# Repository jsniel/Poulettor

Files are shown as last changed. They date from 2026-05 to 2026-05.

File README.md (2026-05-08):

# 🐔 Poulettor

**Open-source automatic chicken coop door controller**

Autonomous ESP32-C3 controller for opening and closing a chicken coop door using a simple DC motor, limit switches and a local Wi‑Fi web interface.

---

## Description

Poulettor is an open-source chicken coop door controller designed to automate a simple sliding or lifting door.

The project uses an **ESP32-C3 Mini**, a **DS3231 RTC**, two relay modules and two limit switches to safely drive a small DC motor in both directions.

Opening and closing times are automatically calculated from local sunrise and sunset, with configurable time offsets from the web interface.

The system is designed to be simple, repairable and independent from the cloud.

---

## Features

- Automatic opening based on sunrise
- Automatic closing based on sunset
- Adjustable morning and evening offsets
- Manual opening button
- Manual closing button
- Local Wi‑Fi configuration portal
- RTC-based scheduling with DS3231
- DC motor control through relays
- Top and bottom limit switch detection
- Motor timeout protection
- Status LED feedback
- No cloud required

---

## Hardware

### Required

- ESP32-C3 Mini
- DS3231 RTC module
- 2 × 5V relay modules
- Small DC gear motor
- 2 × limit switches
- 2 × push buttons
- Status LED + resistor
- Custom PCB or hand wiring
- 5V power source or USB power bank
- Mechanical door, spool, cord and guides

### Enclosure

3D printable enclosure files
- BoitePorte-Corps001.stl
- BoitePorte-Corps002.stl

Editable project with Freecad
- BoitePorte.FCStd

---

## PCB / Electronics

<p align="center">
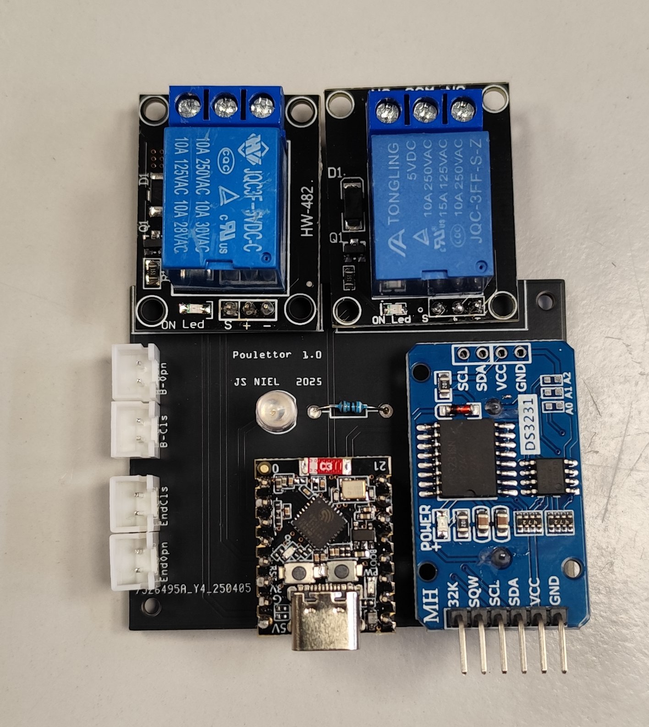
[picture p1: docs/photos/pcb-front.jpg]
  
</p>
<p align="center">
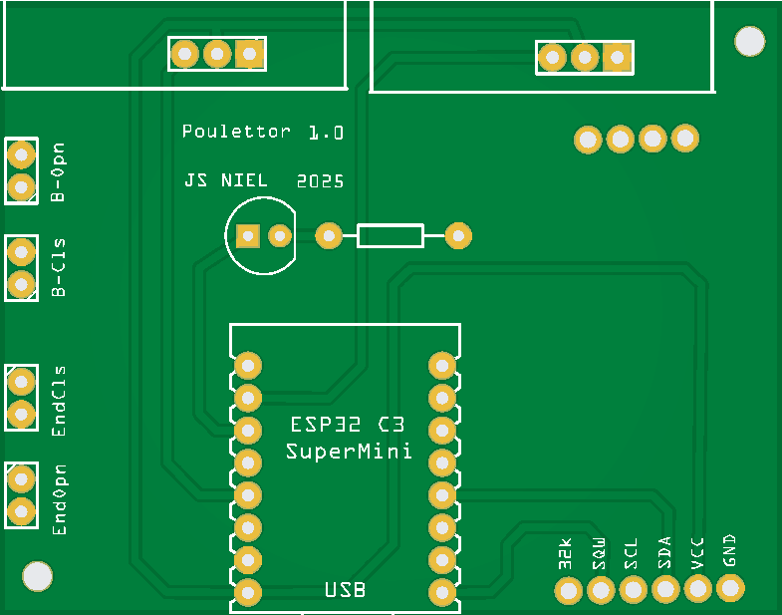
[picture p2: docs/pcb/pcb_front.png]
  
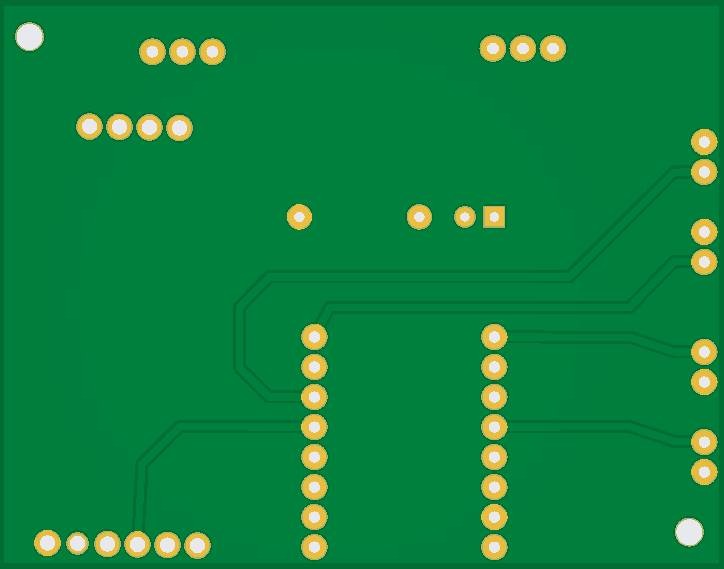
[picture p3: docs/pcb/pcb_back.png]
  
</p>

Hardware files are available in:

```txt
hardware/
```

---

## Prototype Photos

<p align="center">
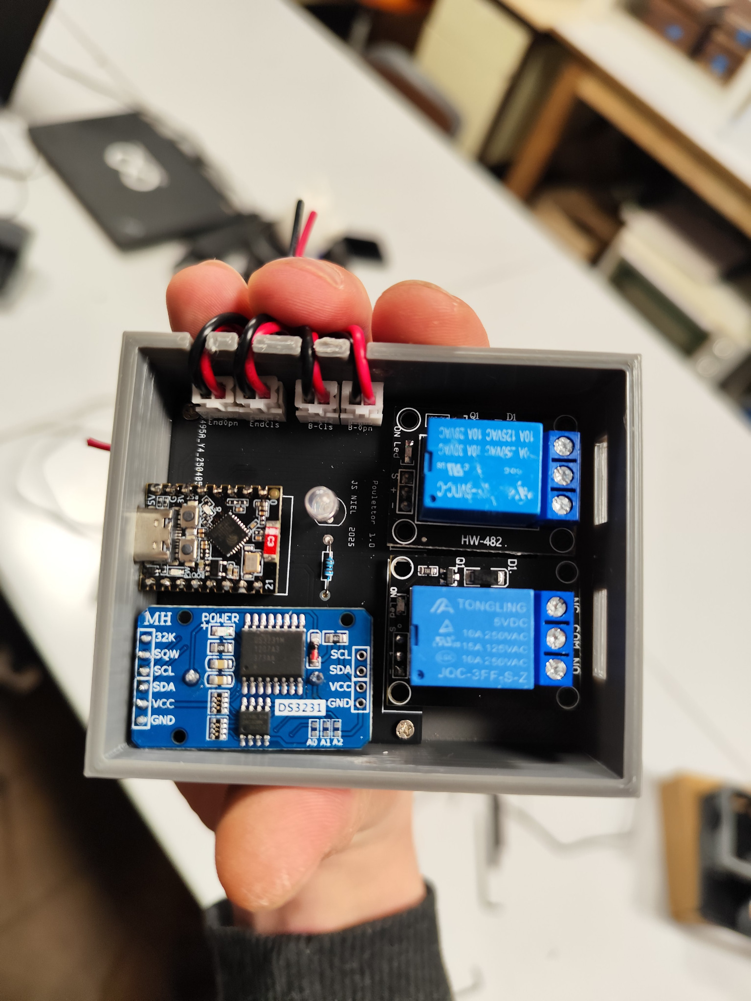
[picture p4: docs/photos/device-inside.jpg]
  
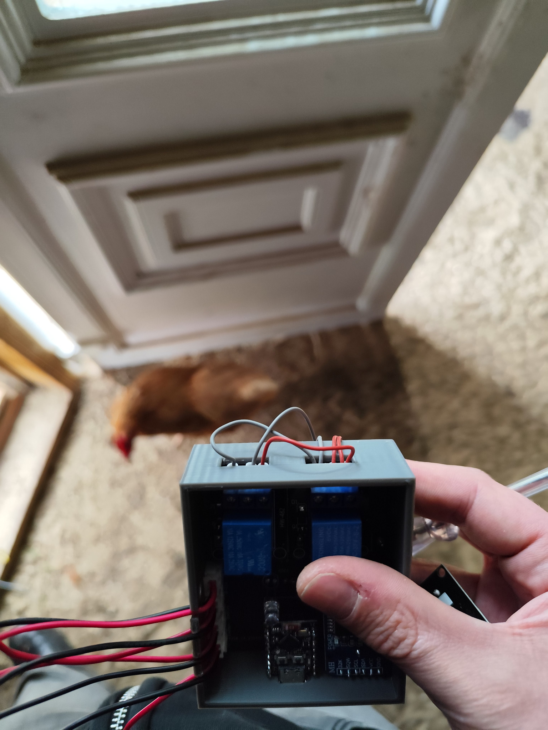
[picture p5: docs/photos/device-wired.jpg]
  
</p>

<p align="center">
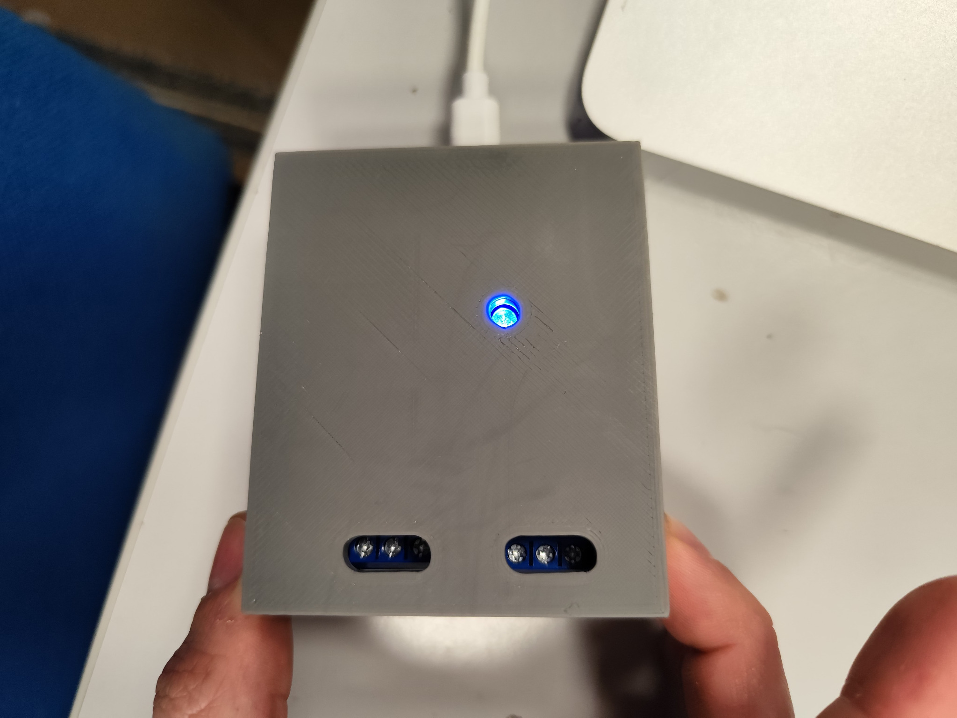
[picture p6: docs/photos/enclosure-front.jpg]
  
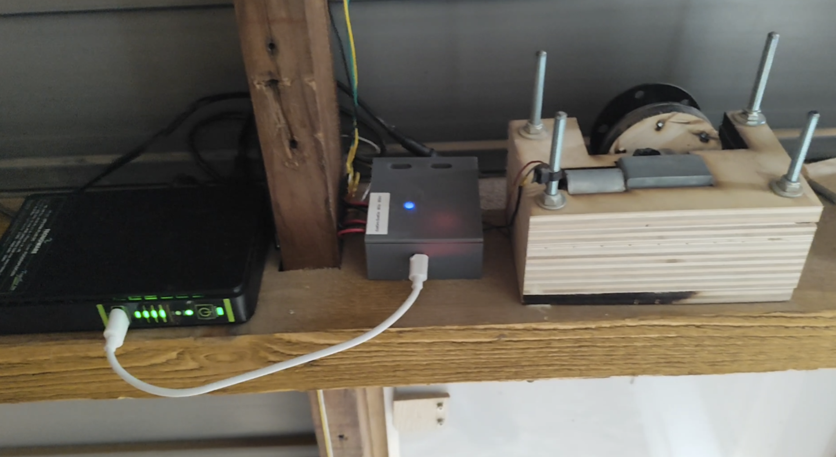
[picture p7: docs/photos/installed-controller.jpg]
  
</p>

---

## Door Mechanism

The door is moved by a simple DC motor and spool mechanism.

<p align="center">
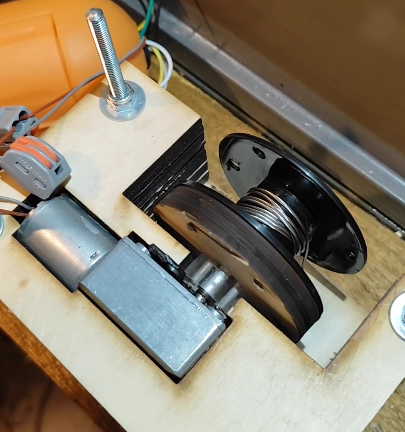
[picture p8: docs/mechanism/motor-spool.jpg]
  
</p>

Two limit switches are used:

- top limit switch: door fully open;
- bottom limit switch: door fully closed.

The firmware stops the motor when a limit switch is reached or after a safety timeout.

---

## Web Interface

You can:

- open the door manually;
- close the door manually;
- view current RTC date and time;
- view calculated sunrise and sunset times;
- configure morning and evening offsets;
- set the RTC time.

<p align="center">
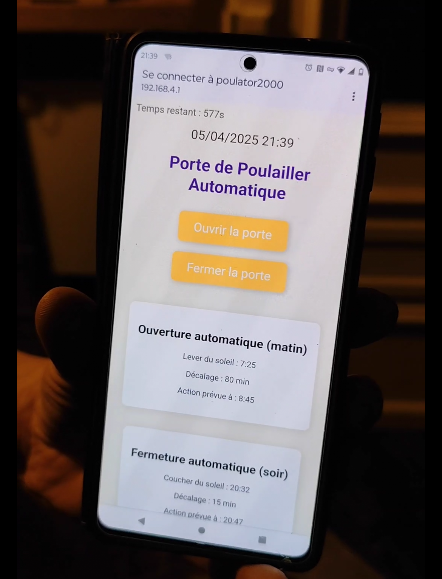
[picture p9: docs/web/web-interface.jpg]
  
</p>

---

## Buttons and LED

### Open / Wi‑Fi button

A short press opens the door manually.

A long press starts the Wi‑Fi configuration portal.

### Close button

A short press closes the door manually.

### LED behavior

| LED behavior | Meaning |
|---|---|
| Solid ON | Automatic mode available |
| Double blink pattern | Wi‑Fi portal active |
| Slow blinking | RTC error |
| Fast blinking | Motor timeout error |

---

## Wi‑Fi portal

Default access point:

```txt
SSID: poulator2000
Password: 123456789
Address: http://192.168.4.1
```

The portal is started with a long press on the open/Wi‑Fi button.

---

## Firmware

Location:

```txt
firmware/PoulettorFW/PoulettorFW.ino
```

---

## Arduino IDE Setup (ESP32‑C3)

### 1. Add ESP32 boards

Open Arduino IDE:

- Go to **File → Preferences**
- In **Additional Boards Manager URLs**, add:

```txt
https://raw.githubusercontent.com/espressif/arduino-esp32/gh-pages/package_esp32_index.json
```

---

### 2. Install ESP32 package

- Go to **Tools → Board → Boards Manager**
- Search: `esp32`
- Install:

```txt
esp32 by Espressif Systems
```

Tested version:

```txt
3.3.5
```

---

### 3. Select board

```txt
ESP32C3 Dev Module
```

---

### 4. Required libraries

Install from Arduino Library Manager:

| Library | Tested version |
|---|---:|
| RTClib by Adafruit | 2.1.4 |
| Adafruit BusIO | 1.17.4 |

---

## Usage

### First boot

1. Power the controller.
2. Hold the open/Wi‑Fi button for about 3 seconds.
3. Connect to the Wi‑Fi access point.
4. Set the RTC time.
5. Configure sunrise and sunset offsets if needed.

---

### Manual control

- Short press on the open button: open the door.
- Short press on the close button: close the door.
- Web interface buttons can also open or close the door.

---

## Known Issues

- No battery level monitoring.
- Wi‑Fi portal has no authentication beyond the AP password.
- Location is currently hardcoded in the firmware.
- The enclosure is a prototype.
- The mechanism must be adapted to each chicken coop door.

---

## Project Structure

```txt
Poulettor/
├── firmware/
├── hardware/
├── enclosure-stl/
├── mechanical/
├── docs/
├── LICENSES/
├── README.md
└── LICENSE
```

---

## Author

**Jean-Sébastien Niel**

GitHub:  
https://github.com/jsniel

---

## License

Poulettor uses separate licenses for firmware and hardware.

### Firmware

GNU General Public License v3.0 or later

```txt
GPL-3.0-or-later
```

### Hardware

CERN Open Hardware Licence Version 2 - Strongly Reciprocal

```txt
CERN-OHL-S-2.0
```

---

## ⚠️ Disclaimer

This project controls a moving mechanical door.

Always test the mechanism safely before using it with animals.

Make sure the door cannot injure animals, block unexpectedly, or trap a chicken during closing.

This project is provided without warranty.

---

## Contributing

Pull requests, mechanical improvements, PCB improvements and firmware improvements are welcome.

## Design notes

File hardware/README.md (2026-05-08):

# Hardware

This directory contains the hardware design files for Poulettor.

---

## Files

| Path | Description |
|---|---|
| `fritzing/PoulaillerPorteGND.fzz` | Fritzing project |
| `pcb/gerber/` | Gerber and drill files |

---

## Hardware overview

The controller uses an ESP32-C3 Mini, a DS3231 RTC, two relay modules and two limit switches.

One relay drives the motor in the opening direction.  
The other relay drives the motor in the closing direction.

The firmware never intentionally activates both motor directions at the same time.

---

## Limit switches

The two limit switches are wired as inputs with internal pull-ups.

| Limit switch | Function |
|---|---|
| Top endstop | Door fully open |
| Bottom endstop | Door fully closed |

Active state is `LOW`.

---

## Safety

Use a motor and power supply adapted to the mechanical load.

Always test the complete mechanism before installing it in a coop.

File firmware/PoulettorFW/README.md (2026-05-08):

# Poulettor firmware

ESP32-C3 firmware for the Poulettor automatic chicken coop door controller.

Firmware by Jean-Sébastien Niel.  
GitHub: https://github.com/jsniel

License: GPL-3.0-or-later

---

## Main behavior

- Calculates sunrise and sunset times from hardcoded latitude and longitude.
- Opens the door in the morning using the sunrise time plus an offset.
- Closes the door in the evening using the sunset time plus an offset.
- Stores offsets in EEPROM.
- Drives a DC motor through two relay outputs.
- Stops motion using top and bottom limit switches.
- Stops the motor after a 15-second timeout if no limit switch is reached.
- Provides a local Wi-Fi web interface when requested by button.

---

## Pin mapping

| Function | GPIO |
|---|---:|
| Open / Wi-Fi button | GPIO10 |
| Close button | GPIO21 |
| Status LED | GPIO2 |
| Top limit switch | GPIO3 |
| Motor open relay | GPIO4 |
| Bottom limit switch | GPIO0 |
| Motor close relay | GPIO1 |
| RTC interrupt | GPIO5 |
| SDA | GPIO8 |
| SCL | GPIO9 |

---

## Arduino IDE setup

Add this URL to Arduino IDE Boards Manager:

```txt
https://raw.githubusercontent.com/espressif/arduino-esp32/gh-pages/package_esp32_index.json
```

Install:

```txt
esp32 by Espressif Systems
```

Select:

```txt
ESP32C3 Dev Module
```

---

## Required libraries

| Library | Tested version |
|---|---:|
| RTClib by Adafruit | 2.1.4 |
| Adafruit BusIO | 1.17.4 |

---

## Default Wi-Fi portal

```txt
SSID: poulator2000
Password: 123456789
IP address: 192.168.4.1
```

---

## Web routes

| Route | Description |
|---|---|
| `/` | Main web page |
| `/ouvrir` | Open the door |
| `/fermer` | Close the door |
| `/setoffset` | Save sunrise/sunset offsets |
| `/settime` | Set RTC time |
| `/datetime` | Return current RTC date and time |
| `/time` | Return current RTC time |

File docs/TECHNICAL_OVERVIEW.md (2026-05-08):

# Technical Overview

This document summarizes the firmware behavior.

---

## Scheduling

The firmware computes sunrise and sunset times from:

- date from DS3231 RTC;
- hardcoded latitude;
- hardcoded longitude;
- daylight saving time detection.

Morning and evening offsets are stored in EEPROM.

---

## Movement state machine

Movement states:

- `AUCUN`
- `OUVERTURE_EN_COURS`
- `FERMETURE_EN_COURS`

Opening:

- stops any current movement;
- checks the top limit switch;
- starts the open relay;
- waits for top endstop or timeout.

Closing:

- stops any current movement;
- checks the bottom limit switch;
- starts the close relay;
- waits for bottom endstop or timeout.

---

## Timeout protection

If a movement lasts more than 15 seconds, the firmware stops the motor and enters timeout error state.

The LED then blinks rapidly.

---

## Web portal

The web server is only started after a long button press.

It provides:

- manual open;
- manual close;
- offset configuration;
- RTC time setting;
- date/time display;
- countdown before portal shutdown.

---

## Important notes

The location is currently hardcoded:

```cpp
const float LATITUDE = 49.4687;
const float LONGITUDE = 1.1178;
```

Future versions could expose location configuration in the web interface.

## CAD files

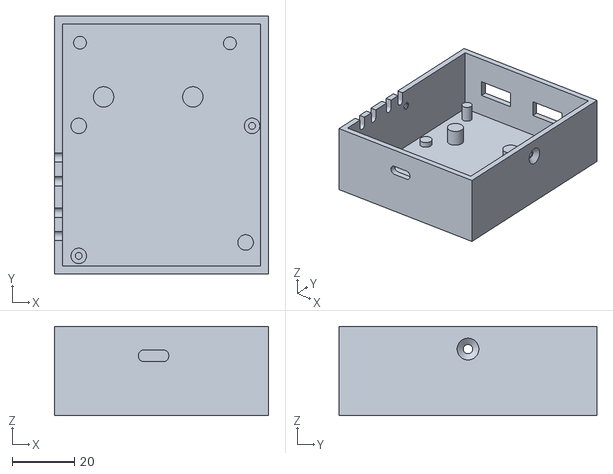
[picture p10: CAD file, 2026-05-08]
enclosure-stl/BoitePorte-Corps001.stl
69.0 x 83.1 x 28.8

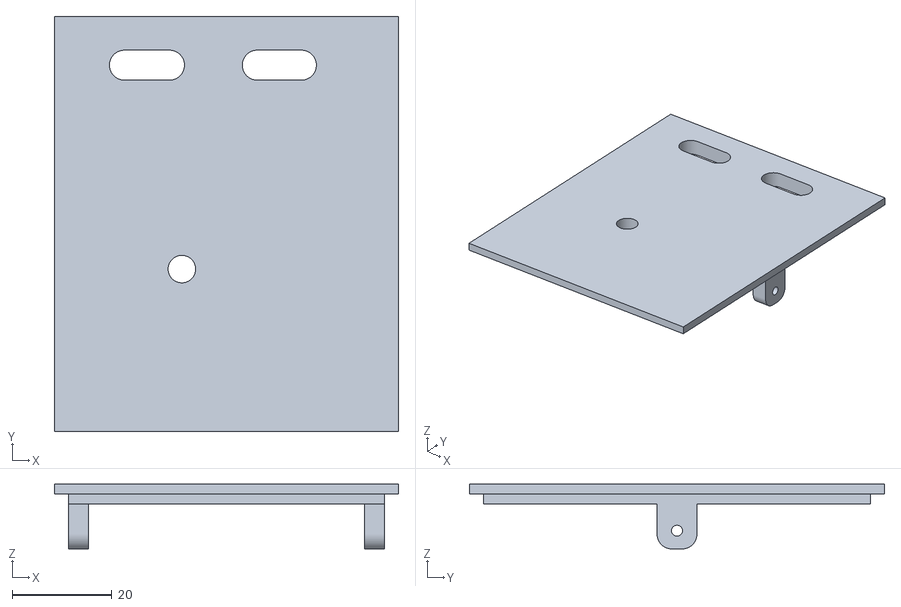
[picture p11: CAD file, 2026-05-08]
enclosure-stl/BoitePorte-Corps002.stl
69.0 x 83.1 x 13.0

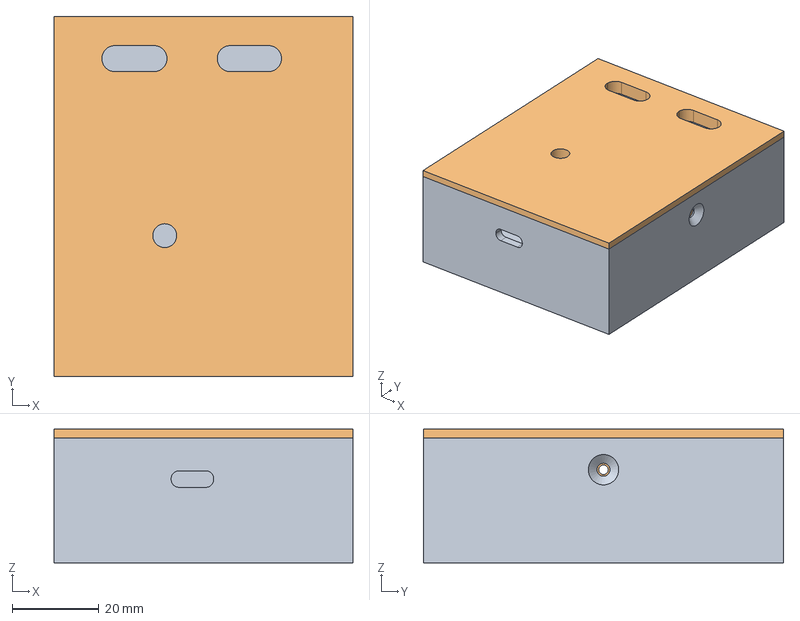
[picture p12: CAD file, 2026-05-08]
enclosure-stl/BoitePorte.FCStd
69.0 x 83.1 x 30.8 mm
Corps001
Corps002

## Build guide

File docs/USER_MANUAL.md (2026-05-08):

# Poulettor User Manual

Poulettor is an automatic chicken coop door controller.

It opens the door in the morning based on sunrise and closes it in the evening based on sunset.

---

## First setup

1. Power the controller.
2. Hold the open/Wi-Fi button for about 3 seconds.
3. Connect to the Wi-Fi network.
4. Open the web interface.
5. Set the RTC time.
6. Adjust the sunrise and sunset offsets if needed.

---

## Wi-Fi portal

```txt
SSID: poulator2000
Password: 123456789
Address: http://192.168.4.1
```

The web portal is started manually with a long press on the open/Wi-Fi button.

---

## Manual control

| Action | Result |
|---|---|
| Short press on open button | Opens the door |
| Short press on close button | Closes the door |
| Long press on open button | Starts Wi-Fi portal |

Manual buttons can interrupt an ongoing movement and reverse direction.

---

## Automatic mode

Poulettor calculates sunrise and sunset times using the date, hardcoded location and daylight saving time.

The user can configure:

- morning offset;
- evening offset.

Example:

```txt
Sunrise: 07:25
Morning offset: +80 min
Door opens: 08:45
```

---

## LED feedback

| LED behavior | Meaning |
|---|---|
| Solid ON | Automatic scheduling available |
| Double blink pattern | Wi-Fi portal active |
| Slow blinking | RTC error |
| Fast blinking | Motor timeout error |

---

## Safety

Check regularly:

- door movement;
- cord condition;
- limit switch position;
- motor mount;
- power supply;
- weather protection.

Never use the system with animals until the mechanism has been tested repeatedly.

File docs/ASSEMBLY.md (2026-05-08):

# Assembly Guide

## 1. Build the electronics

Install:

- ESP32-C3 Mini;
- DS3231 RTC module;
- two relay modules;
- connectors for buttons, limit switches and motor;
- status LED.

---

## 2. Build the mechanism

The prototype uses a DC gear motor with a spool.

The motor winds or unwinds a cord connected to the chicken coop door.

Install:

- a stable motor mount;
- a spool;
- a guide cord;
- a top limit switch;
- a bottom limit switch.

---

## 3. Test without animals

Before real use:

1. Open and close manually.
2. Check both limit switches.
3. Verify the motor timeout.
4. Test several full cycles.
5. Make sure the door cannot jam or injure animals.

---

## 4. Install in the coop

Mount the controller away from rain and dust.

Protect wiring and moving parts from chickens.

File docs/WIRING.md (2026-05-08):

# Wiring Guide

## ESP32-C3 pin mapping

| GPIO | Function |
|---:|---|
| GPIO10 | Open / Wi-Fi button |
| GPIO21 | Close button |
| GPIO2 | Status LED |
| GPIO3 | Top limit switch |
| GPIO4 | Motor open relay |
| GPIO0 | Bottom limit switch |
| GPIO1 | Motor close relay |
| GPIO5 | RTC interrupt pin |
| GPIO8 | I2C SDA |
| GPIO9 | I2C SCL |

---

## Buttons

Buttons use `INPUT_PULLUP`.

Pressed state is `LOW`.

---

## Limit switches

Limit switches use `INPUT_PULLUP`.

Triggered state is `LOW`.

---

## Motor relays

| Relay | Function |
|---|---|
| Motor open relay | Drives the motor to open the door |
| Motor close relay | Drives the motor to close the door |

The firmware ensures that the opposite relay is turned off before starting a direction.

---

## RTC

DS3231 is connected over I2C:

```txt
SDA: GPIO8
SCL: GPIO9
```

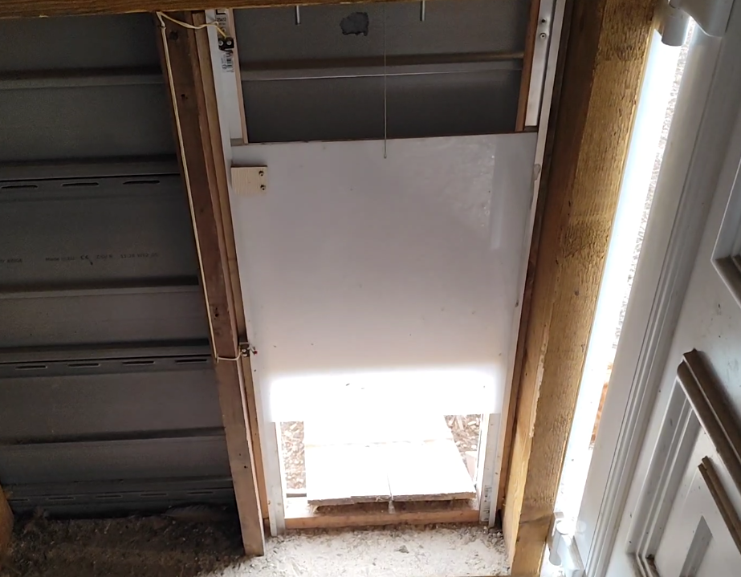
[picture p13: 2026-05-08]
docs/photos/door-installed.jpg

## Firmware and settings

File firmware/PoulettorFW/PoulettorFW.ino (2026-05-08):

/*
 * ============================================================================
 *  Poulettor
 *  Open-source automatic chicken coop door controller
 * ============================================================================
 *
 *  Autonomous ESP32-C3 controller for opening and closing a chicken coop door
 *  using a DC motor, relay outputs, limit switches and DS3231 RTC scheduling.
 *
 *  Project:
 *      https://github.com/jsniel/Poulettor
 *
 *  Author:
 *      Jean-Sébastien Niel
 *
 *  Firmware License:
 *      GNU General Public License v3.0 or later
 *      SPDX-License-Identifier: GPL-3.0-or-later
 *
 *  Hardware License:
 *      CERN Open Hardware Licence Version 2 - Strongly Reciprocal
 *      SPDX-License-Identifier: CERN-OHL-S-2.0
 *
 *  Copyright (C) 2026 Jean-Sébastien Niel
 *
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
 * ============================================================================
 */

#include <WiFi.h>
#include <WebServer.h>
#include <DNSServer.h>
#include <Wire.h>
#include <RTClib.h>
#include <EEPROM.h>


#define BUTTON_PIN 10
#define BUTTON_CLOSE_PIN 21
#define LED_PIN 2
#define ENDSTOP_UP_PIN 3
#define MOTOR_UP_PIN 4
#define ENDSTOP_BOT_PIN 0
#define MOTOR_BOT_PIN 1
#define RTC_INT_PIN 5
#define SDAPIN 8
#define SCLPIN 9
#define EEPROM_SIZE 8
#define EEPROM_OFFSET_LEVER 0       // 2 octets pour offsetLever
#define EEPROM_OFFSET_COUCHER 2     // 2 octets pour offsetCoucher


const float LATITUDE = 49.4687; //Bois-Guillaume
const float LONGITUDE = 1.1178; //Bois-Guillaume


bool horairesCalcules = false;

unsigned long mouvementStart = 0; // à placer en global

RTC_DS3231 rtc;

const char* ssid = "poulator2000";
const char* password = "123456789";

int offsetLever = 0;
int offsetCoucher = 0;


WebServer server(80);
bool webServerEnabled = false;
unsigned long webServerStartTime = 0;
const unsigned long WEB_SERVER_DURATION = 1 * 600 * 1000UL;
DNSServer dnsServer;


enum EtatMouvement {
  AUCUN,
  OUVERTURE_EN_COURS,
  FERMETURE_EN_COURS
};
EtatMouvement mouvement = AUCUN;


IPAddress local_IP(192, 168, 4, 1);
IPAddress gateway(192, 168, 4, 1);
IPAddress subnet(255, 255, 255, 0);

bool lastButtonState = HIGH;
bool buttonStateStable = HIGH;
unsigned long lastDebounceTime = 0;
const unsigned long debounceDelay = 50;
unsigned long lastCheckTime = 0;

bool rtcOk = false;
unsigned long lastBlinkTime = 0;
bool ledState = false;
unsigned long bootTime = 0;

struct AutoFeedConfig {
  bool enabled;
  uint8_t hour;
  uint8_t minute;
};

AutoFeedConfig autoFeed1, autoFeed2;
bool hasDistributed1 = false;
bool hasDistributed2 = false;

String getFormattedTime() {
  DateTime now = rtc.now();
  char buffer[6];
  sprintf(buffer, "%02d:%02d", now.hour(), now.minute());
  return String(buffer);
}



void arreterMoteurs() {
  digitalWrite(MOTOR_UP_PIN, LOW);
  digitalWrite(MOTOR_BOT_PIN, LOW);
  mouvement = AUCUN;
  Serial.println("⛔ Moteurs arrêtés !");
}



void saveOffsetsToEEPROM() {
  EEPROM.writeShort(EEPROM_OFFSET_LEVER, offsetLever);
  EEPROM.writeShort(EEPROM_OFFSET_COUCHER, offsetCoucher);
  EEPROM.commit();
  Serial.printf("💾 Offsets sauvegardés : lever=%d, coucher=%d\n", offsetLever, offsetCoucher);
}

void loadOffsetsFromEEPROM() {
  offsetLever = EEPROM.readShort(EEPROM_OFFSET_LEVER);
  offsetCoucher = EEPROM.readShort(EEPROM_OFFSET_COUCHER);

  // Protection en cas de données corrompues
  if (offsetLever < -120 || offsetLever > 120) offsetLever = 0;
  if (offsetCoucher < -120 || offsetCoucher > 120) offsetCoucher = 0;

  Serial.printf("📥 Offsets chargés depuis EEPROM : lever=%d, coucher=%d\n", offsetLever, offsetCoucher);
}

void mettreAJourHorairesAuto() {
  DateTime now = rtc.now();
  bool ete = isHeureEte(now.day(), now.month(), now.year());

  int leverH, leverM, coucherH, coucherM;
  getSunriseSunset(now.day(), now.month(), now.year(), LATITUDE, LONGITUDE, ete, &leverH, &leverM, &coucherH, &coucherM);

  // Appliquer le décalage sur l'heure de lever
  int minutesLever = leverH * 60 + leverM + offsetLever;
  if (minutesLever < 0) minutesLever += 1440;
  if (minutesLever >= 1440) minutesLever -= 1440;
  autoFeed1.hour = minutesLever / 60;
  autoFeed1.minute = minutesLever % 60;
  autoFeed1.enabled = true;

  // Appliquer le décalage sur l'heure de coucher
  int minutesCoucher = coucherH * 60 + coucherM + offsetCoucher;
  if (minutesCoucher < 0) minutesCoucher += 1440;
  if (minutesCoucher >= 1440) minutesCoucher -= 1440;
  autoFeed2.hour = minutesCoucher / 60;
  autoFeed2.minute = minutesCoucher % 60;
  autoFeed2.enabled = true;

  hasDistributed1 = false;
  hasDistributed2 = false;

  horairesCalcules = true;

  Serial.printf("🕊️ Lever soleil : %02d:%02d | Coucher soleil : %02d:%02d\n", leverH, leverM, coucherH, coucherM);
  Serial.printf("⏰ Action ouverture à %02d:%02d (décalage %+d min)\n", autoFeed1.hour, autoFeed1.minute, offsetLever);
  Serial.printf("⏰ Action fermeture à %02d:%02d (décalage %+d min)\n", autoFeed2.hour, autoFeed2.minute, offsetCoucher);
}


bool isHeureEte(int jour, int mois, int annee) {
  if (mois < 3 || mois > 10) return false;
  if (mois > 3 && mois < 10) return true;

  int dernierDimanche = 31;
  DateTime date;
  if (mois == 3) {
    while (true) {
      date = DateTime(annee, 3, dernierDimanche, 2, 0, 0);
      if (date.dayOfTheWeek() == 0) break;
      dernierDimanche--;
    }
    return (jour >= dernierDimanche);
  } else if (mois == 10) {
    while (true) {
      date = DateTime(annee, 10, dernierDimanche, 3, 0, 0);
      if (date.dayOfTheWeek() == 0) break;
      dernierDimanche--;
    }
    return (jour < dernierDimanche);
  }
  return false;
}


void getSunriseSunset(int day, int month, int year, float latitude, float longitude, bool ete, int* riseH, int* riseM, int* setH, int* setM) {
  float zenith = 90.833;  // Angle officiel

  int N1 = floor(275 * month / 9);
  int N2 = floor((month + 9) / 12);
  int K = 1 + floor((year - 4 * floor(year / 4) + 2) / 3);
  int N = N1 - (K * N2) + day - 30;

  float lngHour = longitude / 15.0;

  auto calcTime = [&](bool sunrise) -> float {
    float t = sunrise ? N + ((6 - lngHour) / 24) : N + ((18 - lngHour) / 24);
    float M = (0.9856 * t) - 3.289;
    float L = fmod(M + (1.916 * sin(M * DEG_TO_RAD)) + (0.020 * sin(2 * M * DEG_TO_RAD)) + 282.634, 360.0);
    float RA = fmod(atan(0.91764 * tan(L * DEG_TO_RAD)) * RAD_TO_DEG, 360.0);
    float Lquadrant = floor(L / 90.0) * 90.0;
    float RAquadrant = floor(RA / 90.0) * 90.0;
    RA = RA + (Lquadrant - RAquadrant);
    RA /= 15.0;

    float sinDec = 0.39782 * sin(L * DEG_TO_RAD);
    float cosDec = cos(asin(sinDec));
    float cosH = (cos(zenith * DEG_TO_RAD) - (sinDec * sin(latitude * DEG_TO_RAD))) / (cosDec * cos(latitude * DEG_TO_RAD));

    if (cosH > 1 || cosH < -1) return -1;  // Soleil ne se lève/couche pas ce jour-là

    float H = sunrise ? 360 - acos(cosH) * RAD_TO_DEG : acos(cosH) * RAD_TO_DEG;
    H = H / 15.0;

    float T = H + RA - (0.06571 * t) - 6.622;
    float UT = fmod(T - lngHour, 24.0);
    if (UT < 0) UT += 24;

    int timezone = ete ? 2 : 1;
    float localT = UT + timezone;
    if (localT >= 24) localT -= 24;

    return localT;
  };

  float riseTime = calcTime(true);
  float setTime = calcTime(false);

  *riseH = int(riseTime);
  *riseM = int((riseTime - *riseH) * 60);
  *setH = int(setTime);
  *setM = int((setTime - *setH) * 60);
}

void ouvrirPorte() {
  if (mouvement != AUCUN) {
    Serial.println("🛑 Interruption en cours, passage à l'ouverture !");
    arreterMoteurs();
    delay(200); // petit délai de sécurité
  }

  if (digitalRead(ENDSTOP_UP_PIN) == LOW) {
    Serial.println("⚠️ Porte déjà ouverte");
    return;
  }

  Serial.println("🔼 Ouverture en cours...");
  digitalWrite(MOTOR_BOT_PIN, LOW); // sécurité
  digitalWrite(MOTOR_UP_PIN, HIGH);
  mouvement = OUVERTURE_EN_COURS;
  mouvementStart = millis(); // pour le timeout
}



void fermerPorte() {
  
  if (mouvement != AUCUN) {
    Serial.println("🛑 Interruption en cours, passage à la fermeture !");
    arreterMoteurs();
    delay(200); // petit délai de sécurité
  }

  if (digitalRead(ENDSTOP_BOT_PIN) == LOW) {
    Serial.println("⚠️ Porte déjà fermée");
    return;
  }

  Serial.println("🔽 Fermeture en cours...");
  digitalWrite(MOTOR_UP_PIN, LOW); // sécurité
  digitalWrite(MOTOR_BOT_PIN, HIGH);
  mouvement = FERMETURE_EN_COURS;
  mouvementStart = millis(); // pour le timeout
}



String generateOptions(int max, int selected) {
  String options;
  for (int i = 0; i <= max; i++) {
    options += "<option value='" + String(i) + "'" + (i == selected ? " selected" : "") + ">" + String(i) + "</option>";
  }
  return options;
}

String generateOffsetOptions(int selected) {
  String options = "";
  for (int i = -120; i <= 120; i += 5) {
    options += "<option value='" + String(i) + "'";
    if (i == selected) options += " selected";
    options += ">" + String(i) + " min</option>";
  }
  return options;
}

String generateHTML() {
  String page = R"rawliteral(
  <!DOCTYPE html>
  <html lang='fr'>
  <head>
    <meta charset='UTF-8'>
    <meta name='viewport' content='width=device-width, initial-scale=1.0'>
    <title>Porte Poulailler</title>
    <style>
      body { font-family: Arial, sans-serif; text-align: center; background-color: #f8f3e3; padding: 20px; }
      h1 { color: #6a4c93; }
      button {
        background-color: #ffcb77;
        border: none;
        padding: 15px 30px;
        font-size: 24px;
        color: white;
        cursor: pointer;
        border-radius: 10px;
        margin: 10px;
        box-shadow: 2px 2px 10px rgba(0,0,0,0.2);
      }
      button:active { background-color: #ff9f1c; }
      .form-container {
        margin-top: 40px;
        background-color: #fff;
        padding: 20px;
        border-radius: 12px;
        display: inline-block;
        box-shadow: 2px 2px 15px rgba(0,0,0,0.1);
      }
      select { padding: 10px; font-size: 16px; margin: 5px; }
    </style>
  </head>
  <body>
    <div style='position: absolute; top: 10px; left: 10px; font-size: 18px; color: #333;'>Temps restant : <span id='countdown'>--</span>s</div>
    <br>
    <div id='datetime' style='font-size: 24px; margin-bottom: 10px;'>--/--/---- --:--</div>
    <h1>Porte de Poulailler Automatique</h1>
    <button onclick="fetch('/ouvrir')">Ouvrir la porte</button>
    <button onclick="fetch('/fermer')">Fermer la porte</button>

    <div class='form-container'>
      <h2>Ouverture automatique (matin)</h2>
      <p>Lever du soleil : %LEVER%</p>
      <p>Décalage : %OFFSET1% min</p>
      <p>Action prévue à : %AUTO1%</p>
    </div>

    <div class='form-container'>
      <h2>Fermeture automatique (soir)</h2>
      <p>Coucher du soleil : %COUCHER%</p>
      <p>Décalage : %OFFSET2% min</p>
      <p>Action prévue à : %AUTO2%</p>
    </div>

    <div class='form-container'>
      <h2>Définir les décalages</h2>
      <form method='GET' action='/setoffset'>
        Lever : <select name='offsetLever'>%OPTIONS1%</select><br>
        Coucher : <select name='offsetCoucher'>%OPTIONS2%</select><br>
        <button type='submit'>Valider</button>
      </form>
    </div>

    <div class='form-container'>
      <h2>Mettre à jour l'heure</h2>
      <form method='GET' action='/settime'>
        Heure: <select name='h'>%HOURS%</select>
        Minute: <select name='m'>%MINUTES%</select>
        <button type='submit'>Définir l'heure</button>
      </form>
    </div>

    <script>
      async function updateClock() {
        try {
          const res = await fetch('/datetime');
          const text = await res.text();
          document.getElementById('datetime').textContent = text;
        } catch (e) {
          document.getElementById('datetime').textContent = '--/--/---- --:--';
        }
      }

      let remaining = parseInt('%SERVER_REMAINING%');
      if (isNaN(remaining)) remaining = 0;

      function updateCountdown() {
        const countdownEl = document.getElementById('countdown');
        if (remaining > 0) {
          countdownEl.textContent = remaining;
          countdownEl.style.color = (remaining <= 10) ? 'red' : '#333';
          remaining--;
        } else {
          countdownEl.textContent = '--';
          countdownEl.style.color = '#333';
        }
      }

      setInterval(updateClock, 10000);
      setInterval(updateCountdown, 1000);
      updateClock();
      updateCountdown();
    </script>
  </body>
  </html>
  )rawliteral";

  DateTime now = rtc.now();
  bool ete = isHeureEte(now.day(), now.month(), now.year());

  int leverH, leverM, coucherH, coucherM;
  getSunriseSunset(now.day(), now.month(), now.year(), LATITUDE, LONGITUDE, ete, &leverH, &leverM, &coucherH, &coucherM);

  page.replace("%LEVER%", String(leverH) + ":" + (leverM < 10 ? "0" : "") + String(leverM));
  page.replace("%COUCHER%", String(coucherH) + ":" + (coucherM < 10 ? "0" : "") + String(coucherM));
  page.replace("%OFFSET1%", String(offsetLever));
  page.replace("%OFFSET2%", String(offsetCoucher));
  page.replace("%AUTO1%", String(autoFeed1.hour) + ":" + (autoFeed1.minute < 10 ? "0" : "") + String(autoFeed1.minute));
  page.replace("%AUTO2%", String(autoFeed2.hour) + ":" + (autoFeed2.minute < 10 ? "0" : "") + String(autoFeed2.minute));
  page.replace("%OPTIONS1%", generateOffsetOptions(offsetLever));
  page.replace("%OPTIONS2%", generateOffsetOptions(offsetCoucher));
  page.replace("%HOURS%", generateOptions(23, now.hour()));
  page.replace("%MINUTES%", generateOptions(59, now.minute()));

  unsigned long remainingTime = WEB_SERVER_DURATION;
  if (webServerEnabled && millis() - webServerStartTime < WEB_SERVER_DURATION) {
    remainingTime = WEB_SERVER_DURATION - (millis() - webServerStartTime);
  }
  page.replace("%SERVER_REMAINING%", String(remainingTime / 1000));

  return page;
}


void setup() {
  Serial.begin(115200);
  delay(2000);

autoFeed1.enabled = true;
autoFeed2.enabled = true;

EEPROM.begin(EEPROM_SIZE);
loadOffsetsFromEEPROM();  // Charger les valeurs à l’allumage


  pinMode(MOTOR_UP_PIN, OUTPUT);
  pinMode(MOTOR_BOT_PIN, OUTPUT);
  pinMode(ENDSTOP_UP_PIN, INPUT_PULLUP);
  pinMode(ENDSTOP_BOT_PIN, INPUT_PULLUP);
  pinMode(BUTTON_PIN, INPUT_PULLUP);
  pinMode(BUTTON_CLOSE_PIN, INPUT_PULLUP);
  pinMode(LED_PIN, OUTPUT);
  digitalWrite(MOTOR_UP_PIN, LOW);
  digitalWrite(MOTOR_BOT_PIN, LOW);

  Wire.begin(SDAPIN, SCLPIN);
  rtcOk = rtc.begin();
  if (!rtcOk) {
  Serial.println("Erreur : RTC non détectée !");
} else {
  if (rtc.lostPower()) rtc.adjust(DateTime(F(__DATE__), F(__TIME__)));
  mettreAJourHorairesAuto();  // <<< APPEL ICI
}
//rtc.adjust(DateTime(F(__DATE__), F(__TIME__)));//////////////////////////////////////////////A supprimer
  server.on("/", HTTP_GET, []() {
    server.send(200, "text/html", generateHTML());
  });
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
void loop() {
  dnsServer.processNextRequest();
  if (webServerEnabled) server.handleClient();

  handleButton();

  // 🧲 Gestion du bouton fermeture
  static bool lastCloseBtn = HIGH;
  bool currentCloseBtn = digitalRead(BUTTON_CLOSE_PIN);
  if (lastCloseBtn == HIGH && currentCloseBtn == LOW) {
    delay(50); // debounce
    if (digitalRead(BUTTON_CLOSE_PIN) == LOW) {
            hasDistributed1 = false;  // <-- désactive la protection
            hasDistributed2 = false;  // <-- désactive la protection
      if (mouvement != AUCUN) {
        Serial.println("🛑 Interruption en cours par bouton fermeture");
        arreterMoteurs();
        delay(200);
        fermerPorte();
      } else {
        Serial.println("👆 Bouton fermeture manuel appuyé !");
        fermerPorte();
      }
    }
  }
  lastCloseBtn = currentCloseBtn;

  // ✅ Fin de course ou timeout
  static bool erreurTimeout = false;

  if (mouvement == OUVERTURE_EN_COURS) {
    if (digitalRead(ENDSTOP_UP_PIN) == LOW) {
    delay(100); // Anti-rebond
      if (digitalRead(ENDSTOP_UP_PIN) == LOW) {
        Serial.println("✅ Porte ouverte (fin de course haut détecté)");
        arreterMoteurs();
      }
    }
else if (millis() - mouvementStart > 15000) {
      Serial.println("❌ Timeout ouverture ! Moteur arrêté.");
      arreterMoteurs();
      erreurTimeout = true;
    }
  }

  if (mouvement == FERMETURE_EN_COURS) {
    if (digitalRead(ENDSTOP_BOT_PIN) == LOW) {
      Serial.println("✅ Porte fermée (fin de course bas détecté)");
      arreterMoteurs();
    } else if (millis() - mouvementStart > 15000) {
      Serial.println("❌ Timeout fermeture ! Moteur arrêté.");
      arreterMoteurs();
      erreurTimeout = true;
    }
  }

  // 🕒 Tâches périodiques toutes les 10 secondes
  unsigned long nowMillis = millis();
  if (nowMillis - lastCheckTime >= 10000) {
    lastCheckTime = nowMillis;

    DateTime now = rtc.now();
    rtcOk = now.isValid() && now.hour() < 24 && now.minute() < 60;

    // 📴 Extinction automatique du serveur web
    if (webServerEnabled && (nowMillis - webServerStartTime > WEB_SERVER_DURATION)) {
      Serial.println("Extinction automatique du serveur web");
      server.stop();
      WiFi.softAPdisconnect(true);
      webServerEnabled = false;
    }

    // 🕛 Mise à jour des horaires à 00:10
    if (rtcOk && now.hour() == 0 && now.minute() == 10 && !horairesCalcules) {
      mettreAJourHorairesAuto();
    }
    if (rtcOk && now.hour() == 0 && now.minute() == 11) {
      horairesCalcules = false;
    }

    // 🚪 Ouverture/Fermeture automatique
    if (!erreurTimeout && rtcOk && nowMillis - bootTime > 5000) {
      // if (autoFeed1.enabled && now.hour() == autoFeed1.hour && now.minute() == autoFeed1.minute && !hasDistributed1) {
      //   ouvrirPorte();
      //   hasDistributed1 = true;
      // }
      // if (autoFeed2.enabled && now.hour() == autoFeed2.hour && now.minute() == autoFeed2.minute && !hasDistributed2) {
      //   fermerPorte();
      //   hasDistributed2 = true;
      // }
      // 🔄 Conversion de l'heure actuelle et des heures cibles en minutes depuis minuit
      int currentMinutes = now.hour() * 60 + now.minute();
      int targetMinutes1 = autoFeed1.hour * 60 + autoFeed1.minute;
      int targetMinutes2 = autoFeed2.hour * 60 + autoFeed2.minute;

      // 🕐 Tolérance : action autorisée pendant la minute prévue (±1 minute)
      if (autoFeed1.enabled && !hasDistributed1 &&
          abs(currentMinutes - targetMinutes1) <= 1) {
        Serial.println("⏰ Déclenchement ouverture automatique (fenêtre ±1 min)");
        ouvrirPorte();
        hasDistributed1 = true;
      }

      if (autoFeed2.enabled && !hasDistributed2 &&
          abs(currentMinutes - targetMinutes2) <= 1) {
        Serial.println("🌙 Déclenchement fermeture automatique (fenêtre ±1 min)");
        fermerPorte();
        hasDistributed2 = true;
      }

    }
  }

  // 💡 LED état système
  if (erreurTimeout) {
    // ⚠️ Clignotement rapide 250 ms
    if (millis() - lastBlinkTime >= 250) {
      lastBlinkTime = millis();
      ledState = !ledState;
      digitalWrite(LED_PIN, ledState);
    }
  }
  else if (!rtcOk || !rtc.begin()) {
    // 🔴 Clignotement lent
    if (millis() - lastBlinkTime >= 500) {
      lastBlinkTime = millis();
      ledState = !ledState;
      digitalWrite(LED_PIN, ledState);
    }
  } else {
    // 🟢 LED fixe ou clignotement serveur
    if (webServerEnabled) {
      unsigned long patternTime = millis() % 1200;
      digitalWrite(LED_PIN, (patternTime < 200 || (patternTime >= 400 && patternTime < 600)) ? HIGH : LOW);
    } else {
      digitalWrite(LED_PIN, (autoFeed1.enabled || autoFeed2.enabled) ? HIGH : LOW);
    }
  }
}



void handleButton() {
  if (millis() - bootTime < 3000) return;

  static bool lastButtonState = HIGH;
  static unsigned long lastDebounceTime = 0;
  static bool buttonStateStable = HIGH;
  static unsigned long buttonPressStart = 0;
  static bool longPressHandled = false;

  bool reading = digitalRead(BUTTON_PIN);

  if (reading != lastButtonState) {
    lastDebounceTime = millis();
  }

  if ((millis() - lastDebounceTime) > debounceDelay) {
    if (reading != buttonStateStable) {
      buttonStateStable = reading;

      if (buttonStateStable == LOW) {
        buttonPressStart = millis();
        longPressHandled = false;
      } else {
        unsigned long pressDuration = millis() - buttonPressStart;
        if (pressDuration < 3000 && !longPressHandled) {
             hasDistributed1 = false;  // <-- désactive la protection
            hasDistributed2 = false;  // <-- désactive la protection
          if (mouvement != AUCUN) {
            Serial.println("🛑 Interruption en cours par bouton ouverture");
            arreterMoteurs();
            delay(200); // petit délai de sécurité
            ouvrirPorte();
          }

          else {
            Serial.println("Appui bouton court détecté - ouverture manuelle");
            ouvrirPorte();
          }
}

        buttonPressStart = 0;
        longPressHandled = false;
      }
    } else if (buttonStateStable == LOW && !longPressHandled) {
      if (millis() - buttonPressStart >= 3000) {
        Serial.println("Appui long détecté - activation du serveur web");
        startWebServer();
        longPressHandled = true;
      }
    }
  }

  lastButtonState = reading;
}

void startWebServer() {
  WiFi.mode(WIFI_AP);
  WiFi.softAPConfig(local_IP, gateway, subnet);
  WiFi.softAP(ssid, password, 11);
  dnsServer.start(53, "", WiFi.softAPIP());
  server.begin();
  webServerEnabled = true;
  webServerStartTime = millis();
  Serial.println("Serveur web démarré.");
}
